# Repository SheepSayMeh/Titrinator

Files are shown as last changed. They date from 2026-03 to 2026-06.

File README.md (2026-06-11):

# Titrinator

An open-source automated titration system built around an ESP32, a peristaltic pump, and a pH probe.

Titrinator combines a motorized burette, wireless control, and real-time data acquisition into a low-cost platform suitable for chemistry education, hobby laboratories, and experimental automation projects.

Unlike traditional manual burettes, Titrinator dispenses titrant using a calibrated peristaltic pump driven by a NEMA17 stepper motor and a TMC2209 driver. The system continuously measures pH, records titration curves, and automatically detects equivalence points while being controlled entirely from a web browser over Bluetooth Low Energy (BLE).

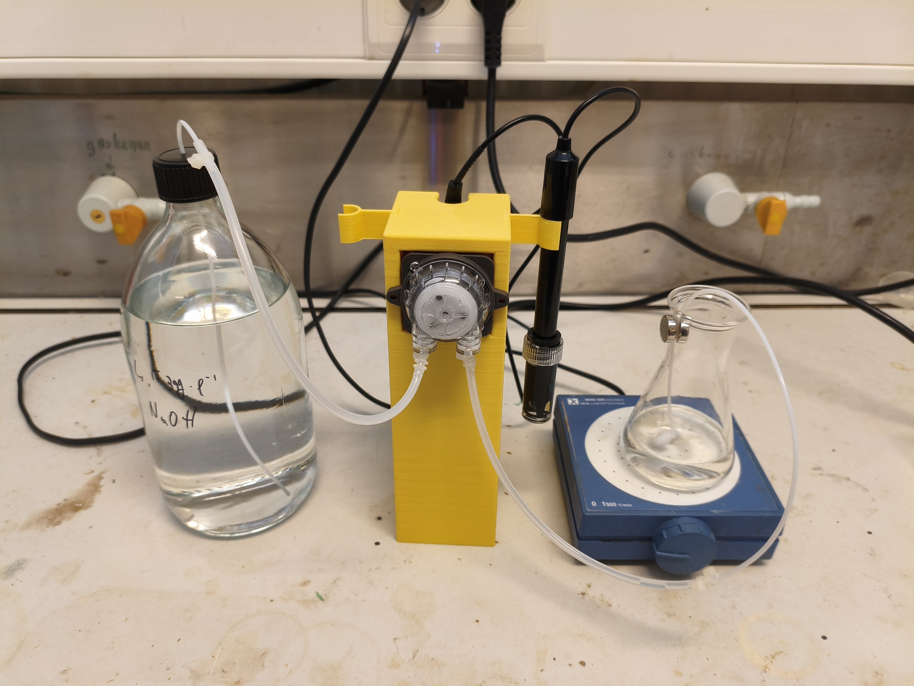
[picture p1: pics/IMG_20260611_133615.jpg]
The Titrinator

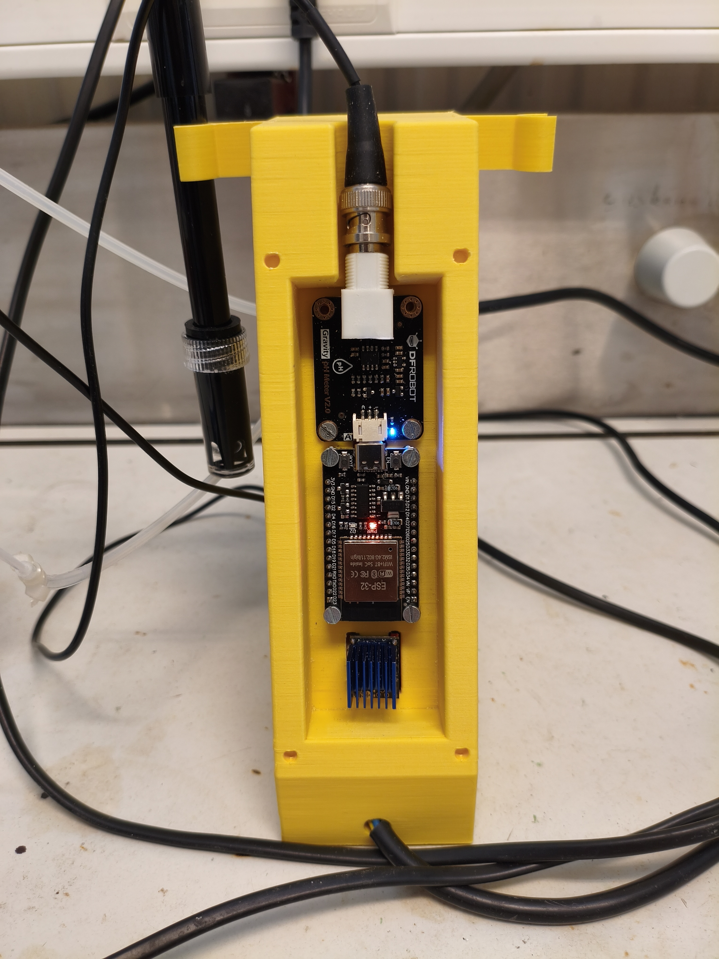
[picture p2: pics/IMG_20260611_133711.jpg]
The Titrinator back

---

## Features

* Automated titrant dispensing
* Real-time pH monitoring
* Live titration curve plotting
* Automatic equivalence point detection
* Wireless browser-based control
* No dedicated application required
* Local data storage on the ESP32
* Export of recorded titrations
* Pump and pH probe calibration routines
* Open-source hardware and software

---

## Hardware Overview

The current implementation uses:

| Component | Description |
| --- | ---|
| ESP32 | Main controller and BLE interface |
| TMC2209 | Stepper motor driver |
| NEMA17 Stepper Motor | Drives the pump |
| Peristaltic Pump | Delivers titrant |
| pH Probe + Interface Board | Measures solution pH |
| 24 V Power Supply | Powers the motor and electronics |
| Step down converter | Steps down to 5v for use by electronics |

### Peristaltic Pump

The system uses a laboratory-style peristaltic pump driven by a NEMA17 stepper motor.

Advantages of a peristaltic pump:

* The reagent only contacts the tubing
* Suitable for corrosive solutions
* No valves required
* Easy tubing replacement
* Simple maintenance
* Accurate volumetric control after calibration

### Architecture

```text
┌─────────────────────────────┐      BLE     ┌──────────────────────────┐
│ Browser Interface           │ ◄──────────► │ ESP32 Firmware           │
│ Vite + JavaScript           │              │ Pump Control             │
│ uPlot                       │              │ pH Measurement           │
│ JSZip                       │              │ Data Logging             │
└─────────────────────────────┘              └──────────────────────────┘
```

The browser acts as the complete user interface. No cloud services, server software, or USB connection are required during operation.

---

## Repository Structure

```text
firmware/        ESP32 firmware
src/             Web application source
public/          Static assets
index.html       Application entry point
vite.config.js   Vite configuration
package.json     Front-end dependencies
```

---

## Browser Compatibility

The user interface relies on the Web Bluetooth API.

Supported:

* Chrome (Windows, Linux, macOS)
* Chrome (Android)
* Chromium-based browsers

iOS:

* Bluefy browser

Not supported:

* Firefox
* Safari

---

## Installation

### Firmware

Install PlatformIO and open the `firmware/` directory.

Upload the firmware:

```bash
pio run --target upload
```

Adjust pin assignments if your hardware differs from the reference design.

### Web Interface

Install dependencies:

```bash
npm install
```

Run the development server:

```bash
npm run dev
```

Build a production version:

```bash
npm run build
```

---

## Calibration

### Pump Calibration

1. Prime the tubing.
2. Run the calibration routine.
3. Collect and weigh the dispensed water.
4. Enter the measured mass.
5. The firmware calculates and stores the conversion factor.

Calibration should be repeated whenever tubing is replaced.

### pH Calibration

The firmware supports both two-point and three-point calibration.

1. Select the calibration mode.
2. Place the probe in each buffer solution.
3. Wait for the reading to stabilise.
4. Confirm the calibration point.

A linearity indicator highlights probe behaviour that deviates from the expected response.

---

## Running a Titration

1. Connect to the ESP32.
2. Verify pump and pH calibrations.
3. Select the titration type.
4. Enter the target volume.
5. Place the probe and dosing tube into the analyte.
6. Start the titration.

During operation the system displays:

* Current pH
* Dispensed volume
* Live titration curve
* Detected equivalence points

Results are stored locally and can later be reviewed or exported.

---

## Data Storage

Titration records are stored in the ESP32 flash memory.

Stored data includes:

* pH measurements
* Dispensed volume
* Titration curves
* Equivalence point calculations

Records can be exported as ZIP archives for further analysis.

---

## Current Limitations

* Temperature compensation is not yet implemented.
* Web Bluetooth support is browser dependent.
* New titration modes currently require firmware modification.
* BLE communication is not authenticated.

---

## Future Development

Planned features include:

* Temperature compensation
* Additional titration methods
* Improved export formats

---

## License

Copyright © 2026 SheepSayMeh

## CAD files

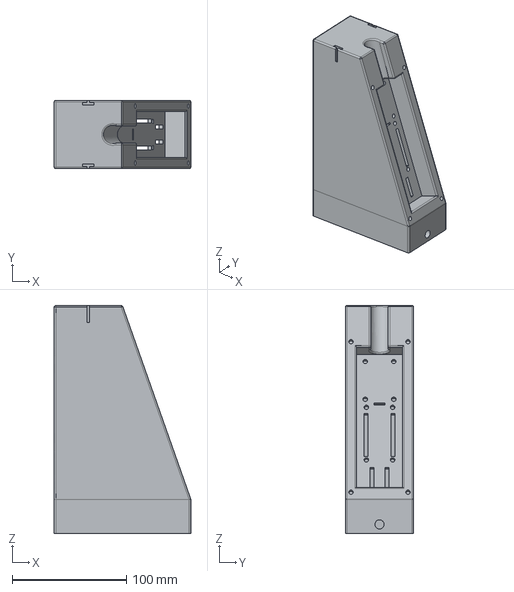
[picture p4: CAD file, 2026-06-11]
CAD files/Titrinator shell-Body.step
120.0 x 60.0 x 200.0 mm

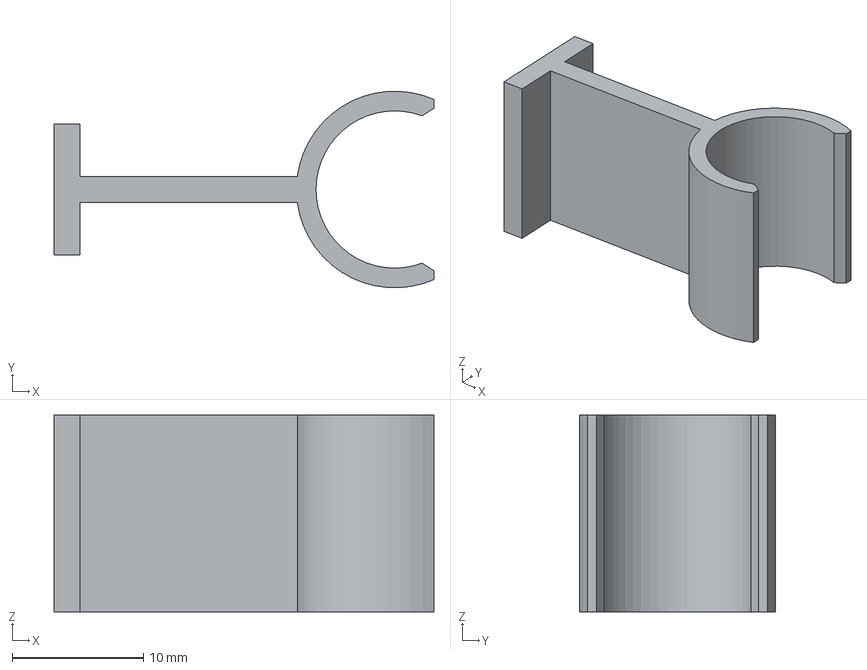
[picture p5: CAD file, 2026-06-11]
CAD files/Titrinator shell- PHProbeHolder.step
29.0 x 15.0 x 15.0 mm

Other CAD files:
CAD files/Titrinator shell.FCStd
CAD files/Titrinator shell- PHProbeHolder.stl
CAD files/Titrinator shell-Body.3mf
CAD files/Titrinator shell-Body.stl

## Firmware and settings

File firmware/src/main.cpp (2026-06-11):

#include <Arduino.h>
#include <NimBLEDevice.h>
#include <Preferences.h>
#include <ArduinoJson.h>
#include <esp_task_wdt.h>
#include <esp_adc_cal.h>
#include <SPIFFS.h>

// ── Device defaults ───────────────────────────────────────────────
#define DEFAULT_DEVICE_NAME "Titrinator-00000"

// ── Pin defaults ─────────────────────────────────────────────────
#if CONFIG_IDF_TARGET_ESP32C3
#define DEFAULT_STEP_PIN    10
#define DEFAULT_DIR_PIN     3
#define DEFAULT_EN_PIN      1
#define DEFAULT_SENSOR_PIN  0
#else
#define DEFAULT_STEP_PIN    27
#define DEFAULT_DIR_PIN     26
#define DEFAULT_EN_PIN      25
#define DEFAULT_SENSOR_PIN  32
#endif
#define DEFAULT_TEMP_PIN    33

// ── Speed constants (µs between steps) ───────────────────────────
#define STEP_DELAY_FLUSH        200
#define STEP_DELAY_NORMAL       1000
#define STEP_DELAY_SLOW         3000
#define STEP_DELAY_MIN          100
#define STEP_DELAY_MAX          10000
#define TIT_SPEED_UPDATE_FREQ   20

// ── Titration speed control ───────────────────────────────────────
#define TIT_MIN_DELAY   400       // µs step delay at zero dU/dV (full speed)
#define TIT_MAX_DELAY   4000      // µs step delay at high dU/dV (slowest)
#define TIT_EXP_SCALE   1500.0f   // |dU/dV| (mV/mL) at which pump reaches TIT_MAX_DELAY

// ── Calibration constants ─────────────────────────────────────────
#define CALIBRATION_STEPS     50000
#define DEFAULT_STEPS_PER_ML  36000.0f
#define ADC_SAMPLES           256     // average this many reads for stability
#define U_EMA_ALPHA           0.2f    // exponential moving average factor for voltage smoothing
#define DUDV_EMA_ALPHA        0.05f    // EMA factor for dU/dV smoothing (higher = more responsive)
#define WDT_YIELD_EVERY       2

// ── BLE UUIDs ────────────────────────────────────────────────────
#define SERVICE_UUID     "1aa974de-6f63-4a76-8a1f-aab707432a77"
#define CMD_CHAR_UUID    "d3951d7f-bf1e-4ad7-9da9-04cef4d5aabb"
#define STATUS_CHAR_UUID "a493eaf8-8638-4375-8445-14fef39fb459"

// ── Globals ──────────────────────────────────────────────────────
NimBLECharacteristic* pStatusChar = nullptr;
Preferences preferences;
bool bleConnected             = false;
volatile bool flushing        = false;
volatile int currentStepDelay = STEP_DELAY_NORMAL;
String serialBuffer           = "";
volatile bool streaming       = false;
const unsigned long STREAM_INTERVAL_MS = 100;
String deviceName             = DEFAULT_DEVICE_NAME;
int stepPin                   = DEFAULT_STEP_PIN;
int dirPin                    = DEFAULT_DIR_PIN;
int enPin                     = DEFAULT_EN_PIN;
int sensorPin                 = DEFAULT_SENSOR_PIN;
int tempPin                   = DEFAULT_TEMP_PIN;

// ── Forward declarations ──────────────────────────────────────────
void respond(const String& msg);

// ── TROWS streaming state (ACK-based flow control) ───────────────
static File titStreamFile;
static int  titStreamId     = -1;
static bool titStreamOpen   = false;
static int  titStreamStride = 1;

void sendNextTrows() {
    if (!titStreamOpen) return;
    String chunk = "TROWS ";
    int    count = 0;
    while (titStreamFile.available() >= 8) {
        uint32_t pos = titStreamFile.position();
        float vol, ph;
        titStreamFile.read((uint8_t*)&vol, 4);
        titStreamFile.read((uint8_t*)&ph,  4);
        String point = (count > 0 ? ";" : "") + String(vol, 4) + "," + String(ph, 3);
        if (count > 0 && chunk.length() + point.length() > 480) {
            titStreamFile.seek(pos);  // won't fit — save this point for the next chunk
            break;
        }
        chunk += point;
        count++;
        if (titStreamStride > 1)
            titStreamFile.seek(titStreamFile.position() + (uint32_t)(titStreamStride - 1) * 8);
    }
    if (count > 0) {
        respond(chunk);
    } else {
        titStreamFile.close();
        titStreamOpen = false;
        respond("TDATA_END " + String(titStreamId));
        titStreamId = -1;
    }
}

// ── pH calibration state ──────────────────────────────────────────
// Stores up to 3 calibration points as (mV, pH) pairs
// Calibration curve: pH = a * mV + b  (linear, 2-point)
//                 or pH = a * mV² + b * mV + c  (quadratic, 3-point)
struct PhCalPoint { uint32_t mV; float ph; };
PhCalPoint phCalPoints[3];
int phCalPointCount = 0;
float phCalA = 0, phCalB = 7, phCalC = 0;  // curve coefficients
bool phCalValid = false;
int phCalDegree = 1;  // 1 = linear, 2 = quadratic
float phCalLinDev = -1;  // linearity deviation % (0 = perfect), -1 = N/A

struct StepRequest {
    long steps;
    int  delayUs;
    bool isCalibration;
    bool isTitration;   // enters autonomous titration loop when true
};

// ── Titration state ───────────────────────────────────────────────
volatile bool  titRunning   = false;
volatile bool  titPause     = false;
volatile bool  titDone      = false;
volatile long  titStepCount = 0;

float titTotalMl      = 0;
float titStepsPerMl   = DEFAULT_STEPS_PER_ML;
int   titDirection    = 1;
int   titId           = 0;
File  titFile;

volatile float titLastAbsDUDV = 0.0f;  // written Core 0, read Core 1 (32-bit atomic)
float mvEma   = -1.0f;                 // EMA of millivolts; -1 = uninitialised sentinel
float dUdVEma = -1.0f;                 // EMA of |dU/dV|; -1 = uninitialised sentinel

// Rolling buffer for dU/dV computation (Core 0 only)
#define DERIV_POINTS 5
#define DERIV_BUF DERIV_POINTS
struct TPoint { float volume; float voltage; };
TPoint derivBuf[DERIV_BUF];
int    derivCount = 0;

QueueHandle_t stepQueue;

// ── ADC calibration ──────────────────────────────────────────────
esp_adc_cal_characteristics_t adcChars;

// ── ADC helper ────────────────────────────────────────────────────
int readADCAveraged(int pin) {
    long sum = 0;
    for (int i = 0; i < ADC_SAMPLES; i++) {
        sum += analogRead(pin);
        delayMicroseconds(100);
    }
    return (int)(sum / ADC_SAMPLES);
}

uint32_t adcToMillivolts(int adc) {
    return esp_adc_cal_raw_to_voltage(adc, &adcChars);
}

// ── Motor helpers ─────────────────────────────────────────────────
void enableMotor()  { digitalWrite(enPin, LOW); }
void disableMotor() { digitalWrite(enPin, HIGH); }

void stepOnce(int delayUs) {
    digitalWrite(stepPin, HIGH);
    delayMicroseconds(delayUs);
    digitalWrite(stepPin, LOW);
    delayMicroseconds(delayUs);
}

// ── Respond ───────────────────────────────────────────────────────
void respond(const String& msg) {
    Serial.println(msg.c_str());
    if (pStatusChar && bleConnected) {
        pStatusChar->setValue(msg.c_str());
        pStatusChar->notify();
    }
}

// ── NVS ───────────────────────────────────────────────────────────
void savePumpCalibration(float stepsPerMl) {
    preferences.begin("titrinator", false);
    preferences.putFloat("steps_per_ml", stepsPerMl);
    preferences.end();
}

float loadPumpCalibration() {
    preferences.begin("titrinator", true);
    float val = preferences.getFloat("steps_per_ml", DEFAULT_STEPS_PER_ML);
    preferences.end();
    return val;
}

void loadDeviceConfig() {
    preferences.begin("titrinator", true);
    deviceName = preferences.getString("device_name", DEFAULT_DEVICE_NAME);
    stepPin    = preferences.getInt("step_pin", DEFAULT_STEP_PIN);
    dirPin     = preferences.getInt("dir_pin", DEFAULT_DIR_PIN);
    enPin      = preferences.getInt("en_pin", DEFAULT_EN_PIN);
    sensorPin  = preferences.getInt("sensor_pin", DEFAULT_SENSOR_PIN);
    tempPin    = preferences.getInt("temp_pin", DEFAULT_TEMP_PIN);
    preferences.end();
}

void saveDeviceConfig(const String& name, int step, int dir, int en, int sensor) {
    preferences.begin("titrinator", false);
    preferences.putString("device_name", name);
    preferences.putInt("step_pin", step);
    preferences.putInt("dir_pin", dir);
    preferences.putInt("en_pin", en);
    preferences.putInt("sensor_pin", sensor);
    preferences.end();
}

void configurePins() {
    pinMode(stepPin, OUTPUT);
    pinMode(dirPin,  OUTPUT);
    pinMode(enPin,   OUTPUT);
    disableMotor();
}

void savePhCalibration() {
    preferences.begin("titrinator", false);
    preferences.putInt("ph_degree", phCalDegree);
    preferences.putFloat("ph_a", phCalA);
    preferences.putFloat("ph_b", phCalB);
    preferences.putFloat("ph_c", phCalC);
    preferences.putFloat("ph_lindev", phCalLinDev);
    preferences.putInt("ph_points", phCalPointCount);
    for (int i = 0; i < phCalPointCount; i++) {
        preferences.putUInt(("ph_mv" + String(i)).c_str(), phCalPoints[i].mV);
        preferences.putFloat(("ph_ph" + String(i)).c_str(), phCalPoints[i].ph);
    }
    preferences.end();
}

void loadPhCalibration() {
    preferences.begin("titrinator", true);
    phCalDegree      = preferences.getInt("ph_degree", 1);
    phCalA           = preferences.getFloat("ph_a", 0);
    phCalB           = preferences.getFloat("ph_b", 7);
    phCalC           = preferences.getFloat("ph_c", 0);
    phCalLinDev      = preferences.getFloat("ph_lindev", -1);
    phCalPointCount  = preferences.getInt("ph_points", 0);
    for (int i = 0; i < phCalPointCount; i++) {
        phCalPoints[i].mV = preferences.getUInt(("ph_mv" + String(i)).c_str(), 0);
        phCalPoints[i].ph = preferences.getFloat(("ph_ph" + String(i)).c_str(), 0);
    }
    phCalValid = (phCalPointCount >= 2);
    preferences.end();
}

// ── SPIFFS space management ───────────────────────────────────────
// Deletes the oldest (lowest-ID) titration file to free space.
// Returns true if a file was deleted.
bool deleteOldestTitration() {
    int oldestId = -1;
    File root = SPIFFS.open("/");
    if (!root || !root.isDirectory()) return false;
    File f = root.openNextFile();
    while (f) {
        String name = f.name();
        if (name.startsWith("tit_") && name.endsWith(".bin")) {
            int id = name.substring(4, name.length() - 4).toInt();
            if (oldestId < 0 || id < oldestId) oldestId = id;
        }
        f.close();
        f = root.openNextFile();
    }
    root.close();
    if (oldestId < 0) return false;
    return SPIFFS.remove("/tit_" + String(oldestId) + ".bin");
}

// ── pH curve fitting ──────────────────────────────────────────────
void fitPhCurve() {
    phCalLinDev = -1;  // reset; only set for 3-point
    if (phCalPointCount == 2) {
        // Linear: pH = a * mV + b
        phCalDegree = 1;
        float x0 = (float)phCalPoints[0].mV, y0 = phCalPoints[0].ph;
        float x1 = (float)phCalPoints[1].mV, y1 = phCalPoints[1].ph;
        phCalA = (y1 - y0) / (x1 - x0);
        phCalB = y0 - phCalA * x0;
        phCalC = 0;
    } else if (phCalPointCount == 3) {
        // Quadratic: pH = a*mV² + b*mV + c via Lagrange interpolation
        phCalDegree = 2;
        float x0 = (float)phCalPoints[0].mV, y0 = phCalPoints[0].ph;
        float x1 = (float)phCalPoints[1].mV, y1 = phCalPoints[1].ph;
        float x2 = (float)phCalPoints[2].mV, y2 = phCalPoints[2].ph;
        float d = (x0-x1)*(x0-x2)*(x1-x2);
        phCalA = (x2*(y1-y0) + x1*(y0-y2) + x0*(y2-y1)) / d;
        phCalB = (x2*x2*(y0-y1) + x1*x1*(y2-y0) + x0*x0*(y1-y2)) / d;
        phCalC = (x1*x2*(x1-x2)*y0 + x0*x2*(x2-x0)*y1 + x0*x1*(x0-x1)*y2) / d;

        // Linearity deviation: (1 - R²) of a linear fit to the 3 points
        float sumX = x0 + x1 + x2, sumY = y0 + y1 + y2;
        float sumXY = x0*y0 + x1*y1 + x2*y2;
        float sumX2 = x0*x0 + x1*x1 + x2*x2;
        float sumY2 = y0*y0 + y1*y1 + y2*y2;
        float num = 3*sumXY - sumX*sumY;
        float den2 = (3*sumX2 - sumX*sumX) * (3*sumY2 - sumY*sumY);
        float r2 = (den2 > 0) ? (num * num) / den2 : 0;
        phCalLinDev = (1.0f - r2) * 100.0f;
    }
    phCalValid = true;
    savePhCalibration();
}

// ── Titration speed controller (called from motor task, Core 1) ───
void updateTitSpeed() {
    float dudv = titLastAbsDUDV;   // 32-bit float read — atomic on ESP32
    float t = fminf(1.0f, dudv / TIT_EXP_SCALE);
    currentStepDelay = (int)(TIT_MIN_DELAY * powf((float)TIT_MAX_DELAY / TIT_MIN_DELAY, t));
}

// ── Motor task ────────────────────────────────────────────────────
void motorTask(void* pvParameters) {
    esp_task_wdt_delete(NULL);
    StepRequest req;
    for (;;) {
        if (xQueueReceive(stepQueue, &req, portMAX_DELAY)) {
            if (req.isTitration) {
                // ── Autonomous titration flow ──────────────────────
                titStepCount = 0;
                currentStepDelay = TIT_MIN_DELAY;
                digitalWrite(dirPin, titDirection > 0 ? HIGH : LOW);
                enableMotor();
                while (titRunning) {
                    if (titPause) {
                        vTaskDelay(pdMS_TO_TICKS(10));
                        continue;
                    }
                    stepOnce(currentStepDelay);
                    titStepCount++;
                    if (titStepCount % TIT_SPEED_UPDATE_FREQ == 0) {
                        updateTitSpeed();
                        float dispensed = (float)titStepCount / titStepsPerMl;
                        if (dispensed >= titTotalMl) titRunning = false;
                    }
                    if (titStepCount % WDT_YIELD_EVERY == 0) taskYIELD();
                }
                disableMotor();
                titDone = true;   // signal main loop to close file and notify

            } else if (req.steps == 0) {
                digitalWrite(dirPin, HIGH);
                enableMotor();
                long i = 0;
                while (flushing) {
                    stepOnce(STEP_DELAY_FLUSH);
                    if (++i % WDT_YIELD_EVERY == 0) taskYIELD();
                }
                disableMotor();
            } else {
                digitalWrite(dirPin, req.steps > 0 ? HIGH : LOW);
                long absSteps = abs(req.steps);
                enableMotor();
                for (long i = 0; i < absSteps; i++) {
                    stepOnce(req.delayUs);
                    if ((i + 1) % WDT_YIELD_EVERY == 0) taskYIELD();
                }
                disableMotor();
                if (req.isCalibration) {
                    respond("CAL_DONE " + String(req.steps));
                } else {
                    respond("DONE " + String(req.steps));
                }
            }
        }
    }
}

// ── Command parser ────────────────────────────────────────────────
void handleCommand(const String& raw) {
    String cmd = raw;
    cmd.trim();
    if (cmd.length() == 0) return;

    if (cmd.startsWith("STEP")) {
        long steps = 0;
        int spaceIdx = cmd.indexOf(' ', 5);
        if (spaceIdx > 0) {
            steps = cmd.substring(5, spaceIdx).toInt();
            int delayUs = constrain(cmd.substring(spaceIdx + 1).toInt(),
                                    STEP_DELAY_MIN, STEP_DELAY_MAX);
            StepRequest req = { steps, delayUs, false };
            xQueueSend(stepQueue, &req, portMAX_DELAY);
        } else {
            steps = cmd.substring(5).toInt();
            StepRequest req = { steps, currentStepDelay, false };
            xQueueSend(stepQueue, &req, portMAX_DELAY);
        }

    } else if (cmd == "FLUSH") {
        flushing = true;
        StepRequest req = { 0, STEP_DELAY_FLUSH, false };
        xQueueSend(stepQueue, &req, portMAX_DELAY);
        respond("FLUSHING");

    } else if (cmd == "STOP") {
        flushing = false;
        disableMotor();
        respond("STOPPED");

    } else if (cmd == "CALIBRATE") {
        StepRequest req = { CALIBRATION_STEPS, STEP_DELAY_NORMAL, true };
        xQueueSend(stepQueue, &req, portMAX_DELAY);

    } else if (cmd.startsWith("SET_SPEED")) {
        String mode = cmd.substring(10);
        mode.trim();
        if (mode == "FAST")        currentStepDelay = STEP_DELAY_FLUSH;
        else if (mode == "NORMAL") currentStepDelay = STEP_DELAY_NORMAL;
        else if (mode == "SLOW")   currentStepDelay = STEP_DELAY_SLOW;
        else { respond("ERR unknown speed: " + mode); return; }
        respond("SPEED " + mode + " " + String(currentStepDelay));

    } else if (cmd.startsWith("SET_DELAY")) {
        int delayUs = constrain(cmd.substring(10).toInt(),
                                STEP_DELAY_MIN, STEP_DELAY_MAX);
        currentStepDelay = delayUs;
        respond("DELAY " + String(currentStepDelay));

    } else if (cmd == "GET_SPEED") {
        String preset = "CUSTOM";
        if (currentStepDelay == STEP_DELAY_FLUSH)  preset = "FAST";
        if (currentStepDelay == STEP_DELAY_NORMAL) preset = "NORMAL";
        if (currentStepDelay == STEP_DELAY_SLOW)   preset = "SLOW";
        respond("SPEED " + preset + " " + String(currentStepDelay));

    } else if (cmd.startsWith("SET_CAL")) {
        float stepsPerMl = cmd.substring(8).toFloat();
        if (stepsPerMl > 0) {
            savePumpCalibration(stepsPerMl);
            respond("CAL_SAVED " + String(stepsPerMl));
        } else {
            respond("ERR invalid calibration value");
        }

    } else if (cmd == "GET_PUMP_CAL") {
        respond("PUMP_CAL " + String(loadPumpCalibration()));

    } else if (cmd == "STREAM_START") {
        streaming = true;
        mvEma = -1.0f;
        // (streaming task uses vTaskDelayUntil; no lastStreamMs needed)
        respond("STREAMING");

    } else if (cmd == "STREAM_STOP") {
        streaming = false;
        respond("STREAM_STOPPED");

    } else if (cmd == "PH_CAL_RESET") {
        phCalPointCount = 0;
        phCalValid = false;
        savePhCalibration();
        respond("PH_CAL_RESET");

    } else if (cmd == "PH_CAL_FIT") {
        if (phCalPointCount < 2) {
            respond("ERR need at least 2 points");
            return;
        }
        fitPhCurve();
        String calMsg = "PH_CAL_SAVED degree=" + String(phCalDegree) +
                " a=" + String(phCalA, 12) +
                " b=" + String(phCalB, 12) +
                " c=" + String(phCalC, 12);
        if (phCalLinDev >= 0)
            calMsg += " lindev=" + String(phCalLinDev, 4);
        respond(calMsg);

    } else if (cmd == "GET_PH_CAL") {
        if (phCalValid) {
            String calInfo = "PH_CAL degree=" + String(phCalDegree) +
                    " a=" + String(phCalA, 12) +
                    " b=" + String(phCalB, 12) +
                    " c=" + String(phCalC, 12) +
                    " points=" + String(phCalPointCount);
            if (phCalLinDev >= 0)
                calInfo += " lindev=" + String(phCalLinDev, 4);
            respond(calInfo);
        } else {
            respond("PH_CAL_NONE");
        }

    } else if (cmd == "STATUS") {
        respond("OK delay=" + String(currentStepDelay) +
                " cal=" + String(loadPumpCalibration()) +
                " ph_cal=" + String(phCalValid ? "yes" : "no"));

    } else if (cmd.startsWith("SET_DEVICE_CONFIG ")) {
        String jsonStr = cmd.substring(18);
        Serial.println("DEBUG: Received SET_DEVICE_CONFIG");
        Serial.println("DEBUG: JSON: " + jsonStr);

        JsonDocument doc;
        DeserializationError err = deserializeJson(doc, jsonStr);
        if (err) {
            Serial.println("DEBUG: JSON parse error: " + String(err.c_str()));
            respond("ERR invalid device config JSON");
            return;
        }

        String name = doc["name"] | "";
        int step    = doc["pins"]["STEP"]   | -1;
        int dir     = doc["pins"]["DIR"]    | -1;
        int en      = doc["pins"]["EN"]     | -1;
        int sensor  = doc["pins"]["SENSOR"] | -1;

        Serial.println("DEBUG: Parsed - name=" + name + " step=" + String(step) + " dir=" + String(dir) + " en=" + String(en) + " sensor=" + String(sensor));

        if (name.length() < 1 || name.length() > 31) {
            respond("ERR device name must be 1-31 chars"); return;
        }
        if (step < 0 || dir < 0 || en < 0 || sensor < 0) {
            respond("ERR pins must be non-negative"); return;
        }
        if (step == dir || step == en || step == sensor || dir == en || dir == sensor || en == sensor) {
            respond("ERR pins must be unique"); return;
        }

        saveDeviceConfig(name, step, dir, en, sensor);
        deviceName = name;
        stepPin = step;
        dirPin = dir;
        enPin = en;
        sensorPin = sensor;
        configurePins();
        respond("DEVICE_CONFIG_SAVED reboot_required=1");

    } else if (cmd == "GET_DEVICE_CONFIG") {
        String msg = "DEVICE_CONFIG name=" + deviceName +
                     " step=" + String(stepPin) +
                     " dir=" + String(dirPin) +
                     " en=" + String(enPin) +
                     " sensor=" + String(sensorPin);
        respond(msg);

    } else if (cmd == "RESTART") {
        respond("RESTARTING");
        delay(100);
        ESP.restart();
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
void loop() {
    // USB serial
    while (Serial.available()) {
        char c = Serial.read();
        if (c == '\n') {
            handleCommand(serialBuffer);
            serialBuffer = "";
        } else if (c != '\r') {
            serialBuffer += c;
        }
    }

    delay(10);
}

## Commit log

2026-05-18 -Added functionality to show memory usage in the history screen, and to evict old titrations when memory is low. This should prevent the "ERR cannot open file" issue when saving titrations, and also 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
    -Added a reconnect screen that appears when the
    app detects an ongoing titration. The device is
    firmware is fully capable of running a titration
    without an active Bluetooth connection, so this
    allows users to either resume the titration or
    interrupt it to start fresh. This should improve
    the user experience when connection to the device
    is lost and regained.
    [main.cpp]
2026-05-19 -Changed back button behaviour on history screen -Slightly changed the variable that governs for EP detection so more subtle EP can be detected.
2026-06-08 Moved CAD files
    [Titrinator shell-Body.stl, Titrinator shell.FCStd]
2026-06-11 Added functionality to flash firmware from the web interface, and added a new PH probe holder design. Also updated the main body design and added some pictures of the prototype.
    [Titrinator shell- PHProbeHolder.step, Titrinator shell- PHProbeHolder.stl, Titrinator shell-Body.3mf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]
